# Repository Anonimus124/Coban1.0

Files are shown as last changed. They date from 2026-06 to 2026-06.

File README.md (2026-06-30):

# Coban 1.0

Coban is a robotic recorder project built around a modified Stagg German-style
soprano recorder, an ESP32-C3 Super Mini, six solenoids, a custom PCB, 3D
printed mounting parts, and a Flutter Android app.

The app sends fingering commands over Bluetooth Low Energy to the ESP32-C3. The
ESP32-C3 then drives six solenoids that cover the recorder holes. The recorder
used here is modified as a six-hole instrument by blocking the thumb hole and
the seventh hole.

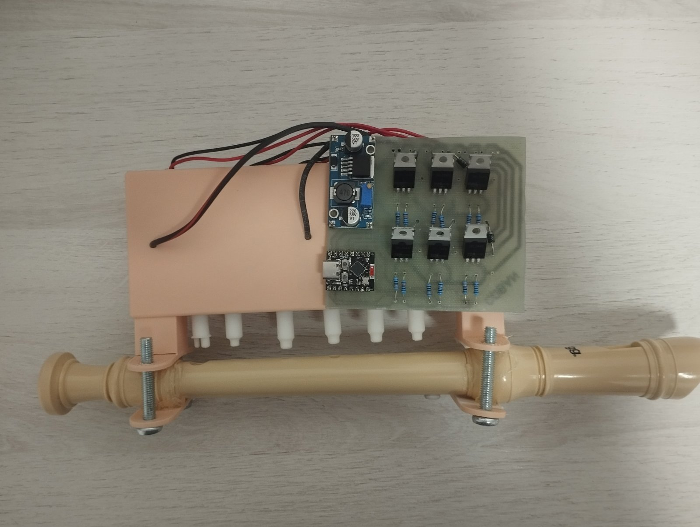
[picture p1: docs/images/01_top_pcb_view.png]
Coban top PCB view


## What Is Included

```text
lib/                         Flutter app source
test/                        Flutter tests
firmware/esp32c3_recorder/   ESP32-C3 Arduino firmware
hardware/                    PCB export and 3MF print files
docs/images/                 Build photos and CAD reference image
release-apk/                 Public no-key Android APK
android/                     Android Flutter project
windows/                     Windows Flutter project
```

The included APK is:

```text
release-apk/Coban-android-arm64-v8a-no-gemini-key.apk
```

This APK is safe to publish because it does not contain a Gemini API key. Manual
mode and Bluetooth control still work, but Gemini sheet-photo translation needs
you to build the app with your own key.

## Main Parts

These are the product links used during the build.

| Part / use | Link |
| --- | --- |
| 18650 Li-ion batteries | https://share.temu.com/AAxxFDRMDZB |
| JF-0530B 5 V push solenoids | https://share.temu.com/nRcJicoiy4B |
| IRLZ44N / IRLZ-series MOSFETs | https://share.temu.com/BM2HjPwDSDB |
| ESP32-C3 Super Mini | https://share.temu.com/fQ0xgR6FktB |
| LM2596 buck converter | https://share.temu.com/UVUPquIY3JB |
| 2-cell 18650 battery holder | https://share.temu.com/3RumAjBXD8B |
| Mini toggle switches | https://share.temu.com/ZeoLe3awByB |
| TP4056 charging modules | https://share.temu.com/UvcupIY5FiB |
| Red/black speaker wire | https://www.temu.com/search_result.html?search_key=2%20core%20speaker%20wire%20red%20black |

Extra parts and materials:

- Stagg Descant Recorder in cream:
  https://www.giggear.co.uk/stagg-descant-recorder-cream.htm
- 6x 10 kOhm resistors.
- 6x 220 Ohm resistors.
- 6x 1N4001 diodes.
- 4x M6 x 40 mm Phillips-head machine screws/bolts for the main recorder clamp.
- 2x M4 x 6 mm Phillips-head machine screws/bolts for the switch plate.
- Double-sided tape for mounting the PCB and battery holder.
- eSun beige PLA for the main body and rigid printed parts.
- BASF Ultrafuse TPS 90A in white for the flexible valves.
- Printed on a Bambu Lab P2S.

The battery holder/station wires were replaced with thicker speaker wire. The
original wires were about 1 mm and did not have enough current capacity for the
solenoids.

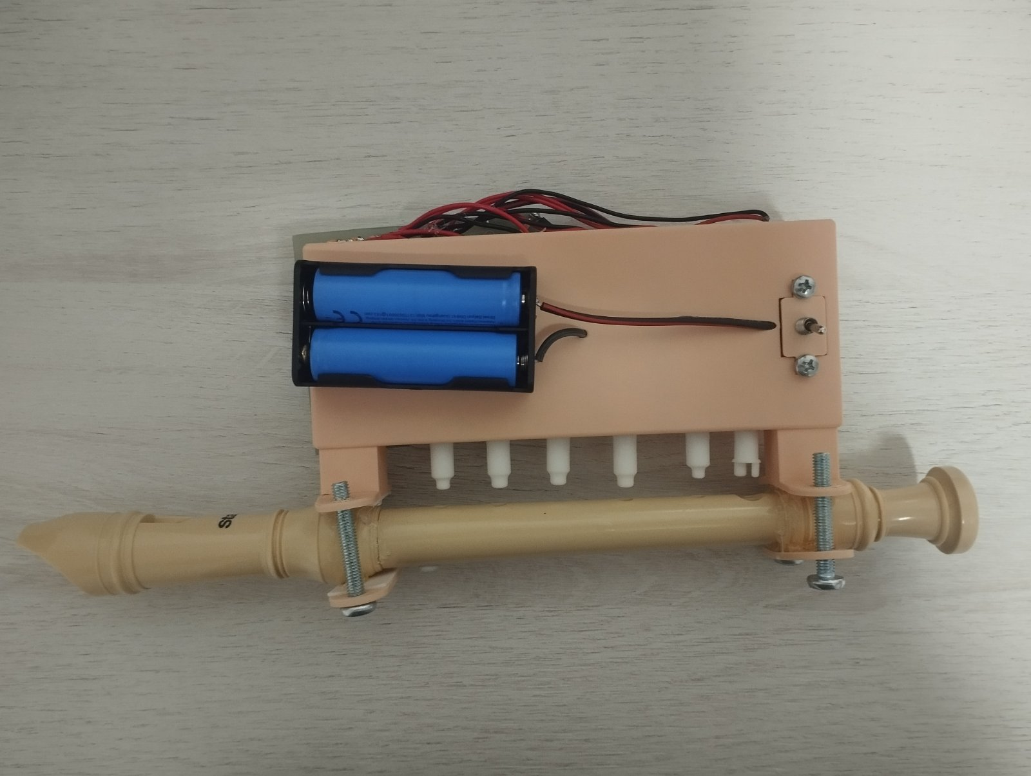
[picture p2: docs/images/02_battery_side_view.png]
Battery side and holder


## Hardware Files

The `hardware/` folder contains:

- `Coban main body.3mf`
- `solenoid spacers.3mf`
- `valves.3mf`
- `PCB_PCB_Coban-1.0_2026-06-30.json`
- `PCB_PCB_Coban-1.0_2026-06-30.svg`

The main body is printed in beige PLA. The valves must be printed from flexible
TPS or TPU. Rigid plastic does not work for the valves because the design relies
on the plastic bending and snapping onto the solenoid.

## Solenoid And Valve Setup

The solenoids are used as push solenoids, not pull solenoids. Install the white
flexible printed valve on the push side of each solenoid, on the small circular
plunger side.

Important: remove the original O-ring from the solenoid before installing the
printed valve. The printed flexible valve replaces the job of the O-ring.

The CAD reference image marks two important things:

- Red marks: possible locations for the solenoid spacer. Use either position to
  lock the solenoid in place so it cannot move.
- Blue mark: the cable path. Route the wires this way because the solenoids are
  being used in the push direction.

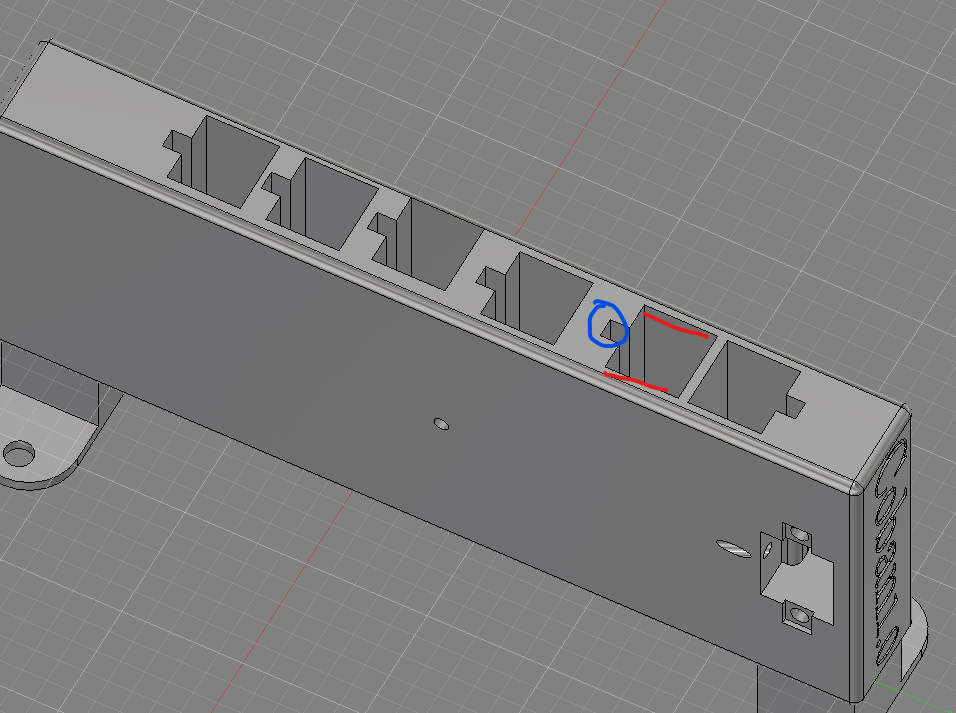
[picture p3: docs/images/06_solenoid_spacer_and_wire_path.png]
Solenoid spacer and cable path reference


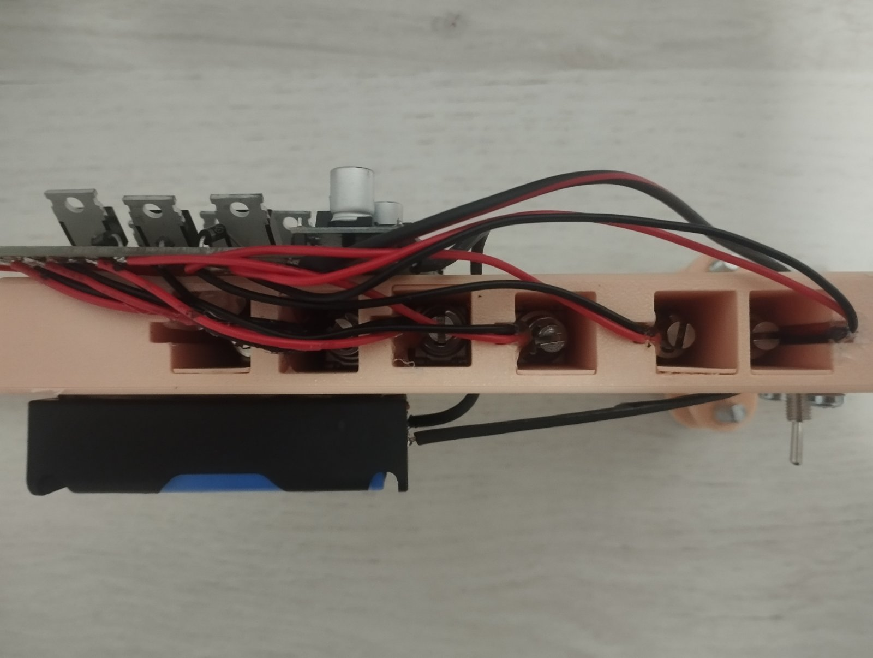
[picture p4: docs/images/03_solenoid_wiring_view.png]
Solenoid wiring view


## Mounting

The main printed body clamps around the recorder with the four M6 x 40 mm
machine screws/bolts. The battery pack sits on the side/top of the printed body.
The PCB and the battery pack are mounted with double-sided tape.

The switch plate uses the two M4 x 6 mm machine screws/bolts.

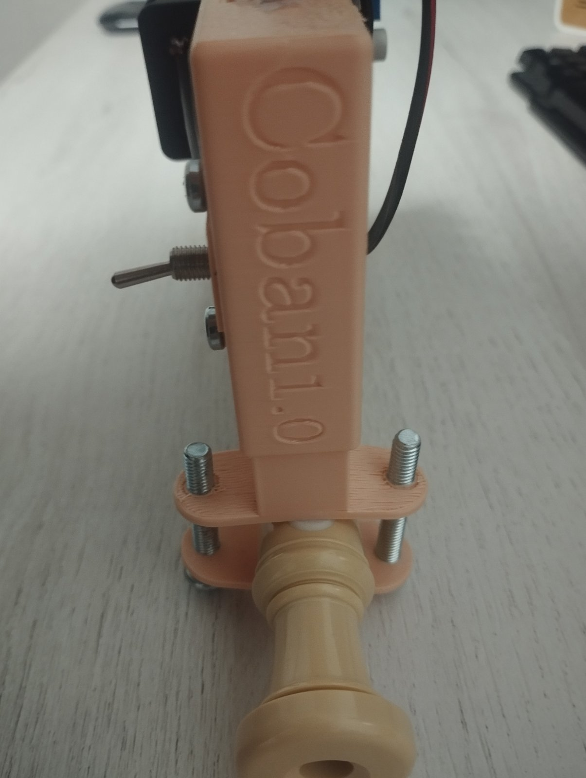
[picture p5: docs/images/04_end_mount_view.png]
End mount view


The upgraded battery wire is shown below. This wire was used because the battery
holder wires were too thin for the solenoid current.

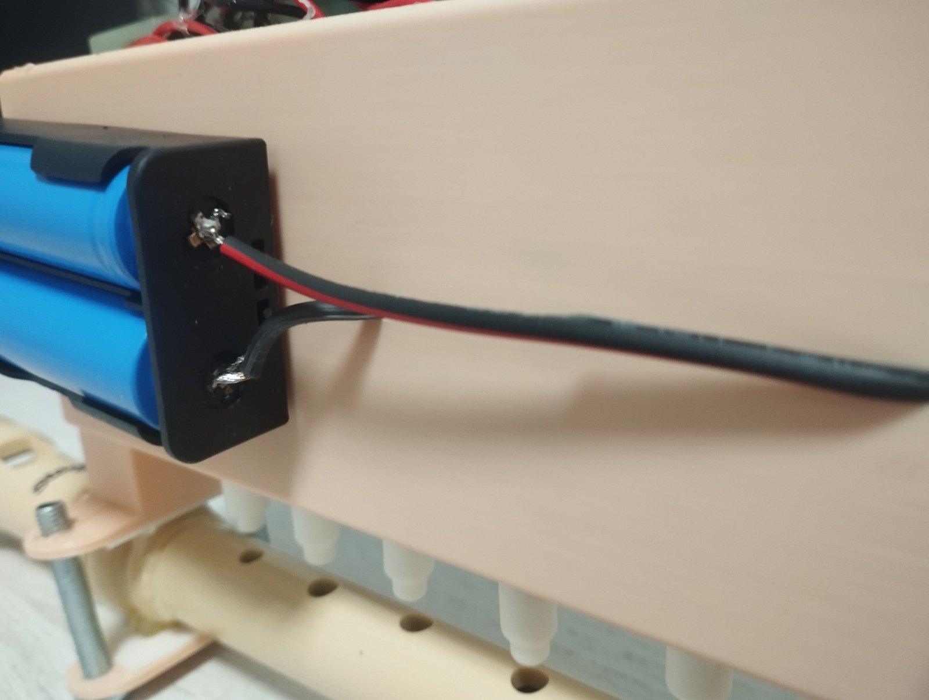
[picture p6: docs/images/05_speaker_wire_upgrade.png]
Speaker wire upgrade


## Solenoid Order And GPIO Mapping

Hole order is from the mouthpiece toward the foot of the recorder.

```text
hole 1 -> GPIO 1
hole 2 -> GPIO 6
hole 3 -> GPIO 5
hole 4 -> GPIO 2
hole 5 -> GPIO 3
hole 6 -> GPIO 4
```

The firmware and app both use this same order.

Do not power the solenoids directly from ESP32 GPIO pins. Use MOSFET/transistor
drivers, flyback diodes, a solenoid power supply, and a shared ground.

## Recorder Fingering Range

This is not a full normal recorder anymore because the thumb hole and seventh
hole are blocked. The app is built around a practical six-hole range:

```text
E4, F4, F#4, G4, G#4/Ab4, A4, A#4/Bb4, B4, C5, C#5, REST
```

Generated songs are simplified into this limited range. Manual songs preserve
the exact hole pattern you enter, including patterns that are not part of the
generated-song note table.

## App Features

- Bluetooth connection to an ESP32-C3 advertising as `Coban`
- Saved songs
- Rename saved songs
- Stop playback
- Manual song creator
- Tap timing recorder
- Delay division for recordings made from slowed-down videos
- Editable millisecond duration for every manual fingering
- Exact manual hole patterns
- Live hole trigger controls
- Sheet-photo to melody conversion with Gemini when built with an API key
- Breath guide for generated songs

## Building The App

Install Flutter, then run:

```powershell
flutter pub get
flutter analyze
flutter test
```

To run or build with Gemini enabled, pass your own Gemini API key with
`--dart-define`. Do not commit API keys.

```powershell
$env:GEMINI_API_KEY = "your-gemini-api-key"
flutter run --dart-define="GEMINI_API_KEY=$env:GEMINI_API_KEY"
```

Release build:

```powershell
$env:GEMINI_API_KEY = "your-gemini-api-key"
flutter build apk --release --split-per-abi --dart-define="GEMINI_API_KEY=$env:GEMINI_API_KEY"
```

For most modern Android phones, use the generated `app-arm64-v8a-release.apk`.

## Firmware Setup

Open this file in Arduino IDE:

```text
firmware/esp32c3_recorder/esp32c3_recorder.ino
```

Arduino IDE requirements:

- ESP32 board package by Espressif Systems
- `ArduinoJson` library
- ESP32-C3 Super Mini or compatible ESP32-C3 board selected

The ESP32-C3 advertises as:

```text
Coban
```

BLE UUIDs:

```text
Service UUID:        4fafc201-1fb5-459e-8fcc-c5c9c331914b
Characteristic UUID: beb5483e-36e1-4688-b7f5-ea07361b26a8
```

The app writes JSON note packets like:

```json
{"t":"note","n":"A4","m":3,"d":500,"b":0.56}
```

Fields:

- `t`: packet type, usually `note`
- `n`: note name for display
- `m`: six-bit fingering mask
- `d`: duration in milliseconds
- `b`: breath intensity for the app UI

## Safety Notes

This is a hobby robotics/electronics project. Check wiring before powering the
solenoids, keep grounds common, use flyback diodes, and make sure the battery
wiring can handle the solenoid current.

The public repository and APK must not contain a Gemini API key.

## License

This project is released under the MIT License. See `LICENSE`.

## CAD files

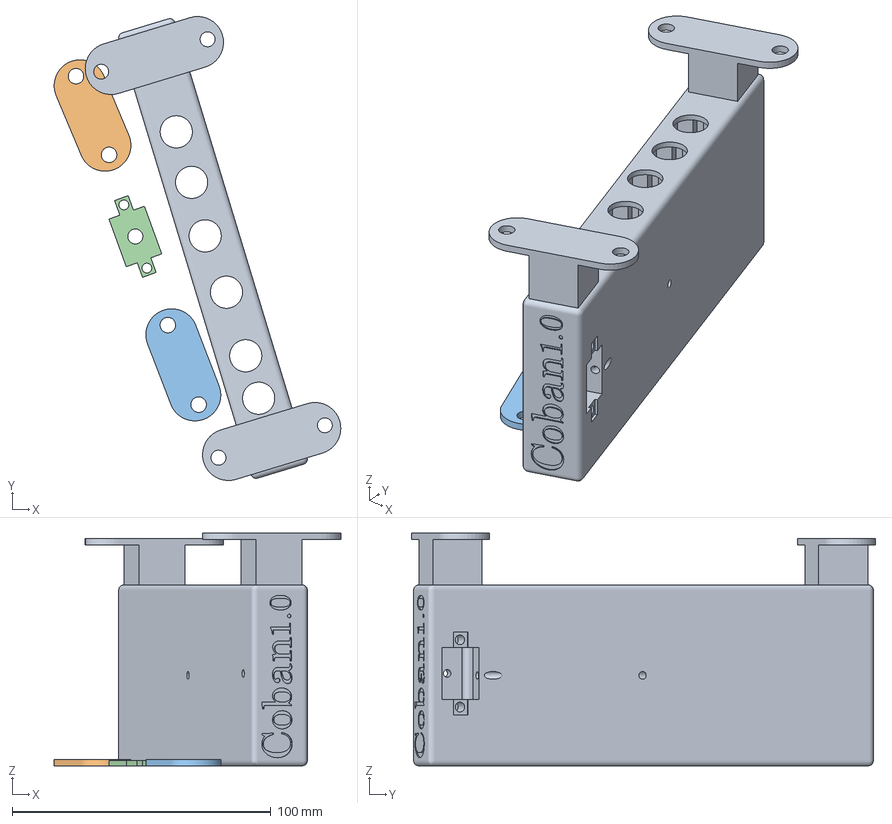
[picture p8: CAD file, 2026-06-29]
hardware/Coban main body.3mf
110.9 x 179.4 x 90.0 mm

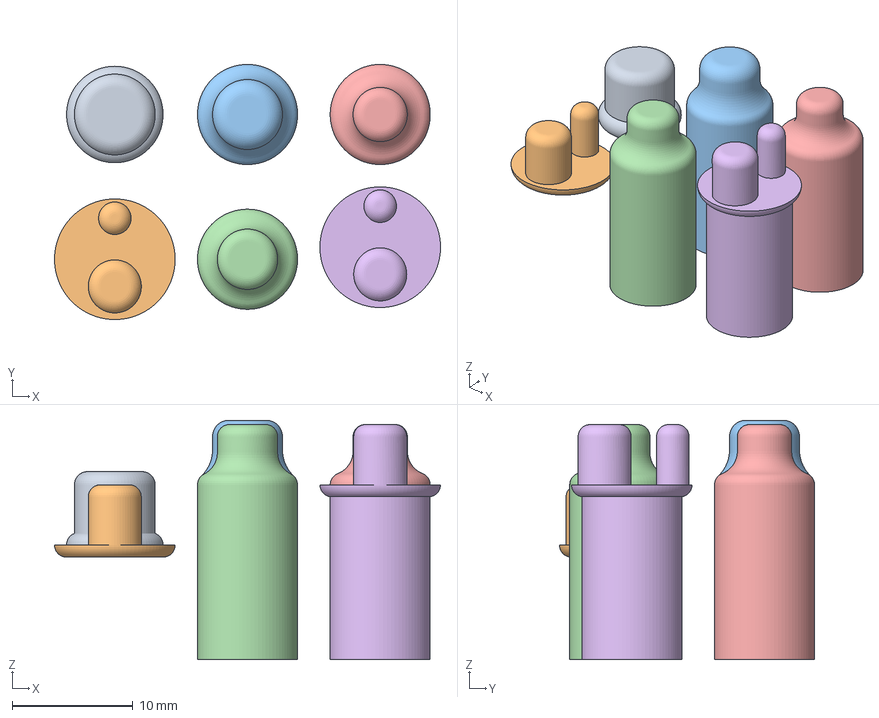
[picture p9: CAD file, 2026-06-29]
hardware/valves.3mf
32.0 x 21.1 x 19.9 mm

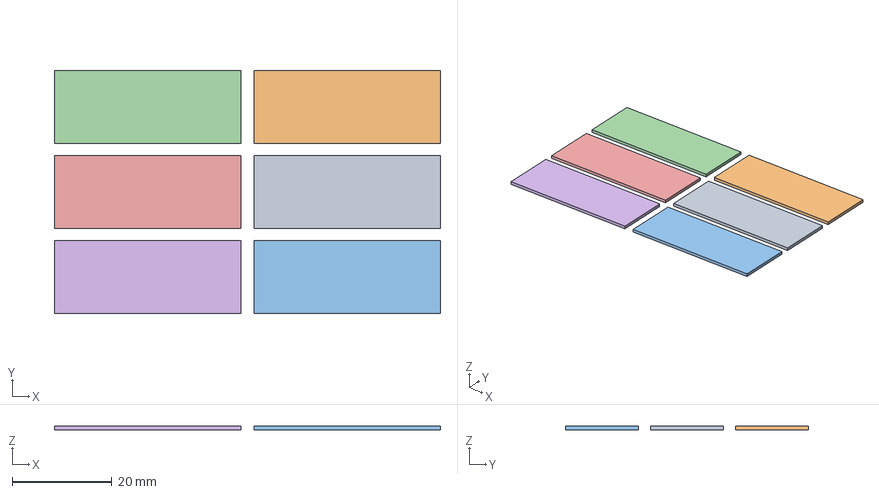
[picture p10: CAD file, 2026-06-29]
hardware/solenoid spacers.3mf
77.3 x 48.6 x 0.8 mm

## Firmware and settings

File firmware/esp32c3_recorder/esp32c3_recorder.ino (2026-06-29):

/*
  Coban ESP32-C3 Super Mini firmware.

  BLE protocol follows the friend-project pattern:
    Device name: Coban
    Service UUID:        4fafc201-1fb5-459e-8fcc-c5c9c331914b
    Characteristic UUID: beb5483e-36e1-4688-b7f5-ea07361b26a8

  The Flutter app writes JSON to the characteristic:
    {"t":"note","n":"A5","m":31,"d":500,"b":0.68}

  Fields:
    t = packet type, "note"
    n = display note name
    m = fingering bitmask, bit 0..5 map to holes from mouthpiece to foot
    d = duration in milliseconds
    b = breath intensity for the app UI, ignored by firmware

  Correct solenoid order:
    hole 1 GPIO 1, hole 2 GPIO 6, hole 3 GPIO 5,
    hole 4 GPIO 2, hole 5 GPIO 3, hole 6 GPIO 4.

  Hardware note:
    Do not drive solenoids directly from ESP32 GPIO pins. Use MOSFET/transistor
    drivers, flyback diodes, and a solenoid power supply with a shared ground.
*/

#include <Arduino.h>
#include <ArduinoJson.h>
#include <BLE2902.h>
#include <BLEDevice.h>
#include <BLEServer.h>
#include <BLEUtils.h>

static const char *DEVICE_NAME = "Coban";

static const char *SERVICE_UUID = "4fafc201-1fb5-459e-8fcc-c5c9c331914b";
static const char *CHARACTERISTIC_UUID = "beb5483e-36e1-4688-b7f5-ea07361b26a8";

static const uint8_t SOLENOID_COUNT = 6;
static const uint8_t MAX_ACTIVE_SOLENOIDS = 6;
static const uint8_t SOLENOID_PINS[SOLENOID_COUNT] = {1, 6, 5, 2, 3, 4};

// Change these if your driver board is active-low.
static const uint8_t SOLENOID_ACTIVE_LEVEL = HIGH;
static const uint8_t SOLENOID_INACTIVE_LEVEL = LOW;

BLEServer *bleServer = nullptr;
BLECharacteristic *commandCharacteristic = nullptr;

bool deviceConnected = false;
bool noteActive = false;
uint32_t noteOffAtMs = 0;

uint8_t countActiveBits(uint8_t mask) {
  uint8_t count = 0;
  for (uint8_t i = 0; i < SOLENOID_COUNT; i++) {
    if ((mask & (1 << i)) != 0) {
      count++;
    }
  }
  return count;
}

void notifyStatus(const char *message) {
  Serial.println(message);

  if (deviceConnected && commandCharacteristic != nullptr) {
    StaticJsonDocument<96> doc;
    doc["t"] = "status";
    doc["v"] = message;

    char buffer[96];
    serializeJson(doc, buffer);
    commandCharacteristic->setValue(buffer);
    commandCharacteristic->notify();
  }
}

void allSolenoidsOff() {
  for (uint8_t i = 0; i < SOLENOID_COUNT; i++) {
    digitalWrite(SOLENOID_PINS[i], SOLENOID_INACTIVE_LEVEL);
  }
  noteActive = false;
}

bool applyFingering(uint8_t mask, uint16_t durationMs) {
  mask &= 0x3F;

  const uint8_t activeCount = countActiveBits(mask);
  if (activeCount > MAX_ACTIVE_SOLENOIDS) {
    allSolenoidsOff();
    notifyStatus("ERR_LIMIT");
    return false;
  }

  for (uint8_t i = 0; i < SOLENOID_COUNT; i++) {
    const bool isActive = (mask & (1 << i)) != 0;
    digitalWrite(
      SOLENOID_PINS[i],
      isActive ? SOLENOID_ACTIVE_LEVEL : SOLENOID_INACTIVE_LEVEL
    );
  }

  if (durationMs == 0 || activeCount == 0) {
    noteActive = false;
    if (activeCount == 0) {
      allSolenoidsOff();
    }
    return true;
  }

  noteActive = true;
  noteOffAtMs = millis() + durationMs;
  return true;
}

bool handleJsonCommand(const String &value) {
  StaticJsonDocument<192> doc;
  const DeserializationError error = deserializeJson(doc, value);
  if (error) {
    notifyStatus("ERR_JSON");
    return false;
  }

  const char *type = doc["t"] | "";
  if (strcmp(type, "note") != 0) {
    notifyStatus("ERR_TYPE");
    return false;
  }

  const uint8_t mask = doc["m"] | 0;
  const uint16_t durationMs = doc["d"] | 0;
  return applyFingering(mask, durationMs);
}

// Backward compatibility with the earlier 4-byte prototype packet.
bool handleBinaryCommand(const String &value) {
  if (value.length() < 4) {
    notifyStatus("ERR_SHORT_PACKET");
    return false;
  }

  const uint8_t magic = static_cast<uint8_t>(value[0]);
  if (magic != 0x52) {
    notifyStatus("ERR_BAD_MAGIC");
    return false;
  }

  const uint8_t mask = static_cast<uint8_t>(value[1]);
  const uint16_t durationMs =
      static_cast<uint8_t>(value[2]) |
      (static_cast<uint16_t>(static_cast<uint8_t>(value[3])) << 8);
  return applyFingering(mask, durationMs);
}

class ServerCallbacks : public BLEServerCallbacks {
  void onConnect(BLEServer *server) override {
    deviceConnected = true;
    notifyStatus("CONNECTED");
  }

  void onDisconnect(BLEServer *server) override {
    deviceConnected = false;
    allSolenoidsOff();
    Serial.println("DISCONNECTED");
    BLEDevice::startAdvertising();
  }
};

class CommandCallbacks : public BLECharacteristicCallbacks {
  void onWrite(BLECharacteristic *characteristic) override {
    const String value = characteristic->getValue();
    if (value.length() == 0) {
      notifyStatus("ERR_EMPTY");
      return;
    }

    const bool ok = value[0] == '{'
        ? handleJsonCommand(value)
        : handleBinaryCommand(value);

    if (ok) {
      notifyStatus("OK");
    }
  }
};

void setupPins() {
  for (uint8_t i = 0; i < SOLENOID_COUNT; i++) {
    digitalWrite(SOLENOID_PINS[i], SOLENOID_INACTIVE_LEVEL);
    pinMode(SOLENOID_PINS[i], OUTPUT);
    digitalWrite(SOLENOID_PINS[i], SOLENOID_INACTIVE_LEVEL);
  }
}

void setupBle() {
  BLEDevice::init(DEVICE_NAME);
  BLEDevice::setPower(ESP_PWR_LVL_P9);

  bleServer = BLEDevice::createServer();
  bleServer->setCallbacks(new ServerCallbacks());

  BLEService *service = bleServer->createService(SERVICE_UUID);

  commandCharacteristic = service->createCharacteristic(
    CHARACTERISTIC_UUID,
    BLECharacteristic::PROPERTY_READ |
      BLECharacteristic::PROPERTY_WRITE |
      BLECharacteristic::PROPERTY_WRITE_NR |
      BLECharacteristic::PROPERTY_NOTIFY
  );
  commandCharacteristic->addDescriptor(new BLE2902());
  commandCharacteristic->setCallbacks(new CommandCallbacks());
  commandCharacteristic->setValue("{\"t\":\"status\",\"v\":\"READY\"}");

  service->start();

  BLEAdvertising *advertising = BLEDevice::getAdvertising();
  advertising->addServiceUUID(SERVICE_UUID);
  advertising->setScanResponse(false);
  advertising->setMinPreferred(0x0);

  BLEDevice::startAdvertising();
  Serial.println("BLE advertising as Coban");
}

void setup() {
  Serial.begin(115200);
  delay(250);

  setupPins();
  setupBle();

  Serial.println("Coban recorder firmware ready");
}

void loop() {
  if (noteActive && static_cast<int32_t>(millis() - noteOffAtMs) >= 0) {
    allSolenoidsOff();
  }

  delay(2);
}

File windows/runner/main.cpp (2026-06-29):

#include <flutter/dart_project.h>
#include <flutter/flutter_view_controller.h>
#include <windows.h>

#include "flutter_window.h"
#include "utils.h"

int APIENTRY wWinMain(_In_ HINSTANCE instance, _In_opt_ HINSTANCE prev,
                      _In_ wchar_t *command_line, _In_ int show_command) {
  // Attach to console when present (e.g., 'flutter run') or create a
  // new console when running with a debugger.
  if (!::AttachConsole(ATTACH_PARENT_PROCESS) && ::IsDebuggerPresent()) {
    CreateAndAttachConsole();
  }

  // Initialize COM, so that it is available for use in the library and/or
  // plugins.
  ::CoInitializeEx(nullptr, COINIT_APARTMENTTHREADED);

  flutter::DartProject project(L"data");

  std::vector<std::string> command_line_arguments =
      GetCommandLineArguments();

  project.set_dart_entrypoint_arguments(std::move(command_line_arguments));

  FlutterWindow window(project);
  Win32Window::Point origin(10, 10);
  Win32Window::Size size(1280, 720);
  if (!window.Create(L"Coban", origin, size)) {
    return EXIT_FAILURE;
  }
  window.SetQuitOnClose(true);

  ::MSG msg;
  while (::GetMessage(&msg, nullptr, 0, 0)) {
    ::TranslateMessage(&msg);
    ::DispatchMessage(&msg);
  }

  ::CoUninitialize();
  return EXIT_SUCCESS;
}

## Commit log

2026-06-29 Initial Coban project release
    [Coban main body.3mf, solenoid spacers.3mf, valves.3mf]
2026-06-30 Clarify Temu parts in BOM
2026-06-30 Add missing resistor and diode parts
2026-06-30 Move speaker wire into parts table
